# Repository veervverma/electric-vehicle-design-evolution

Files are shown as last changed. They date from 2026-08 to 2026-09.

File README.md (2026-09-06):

# Electric Vehicle Design Evolution

An educational CAD, visualization, 3D-printing, and conceptual aerodynamics portfolio tracing the development of an electric sedan and a Formula-style electric race-car study.

## Explore the project

- **[Interactive browser gallery](https://veervverma.github.io/electric-vehicle-design-evolution/):** displays both GLB and STL models, plays available glTF animations, and exposes every viewable model through a searchable catalog.
- **[Interactive W11 aerodynamic lab](https://veervverma.github.io/electric-vehicle-design-evolution/wind-tunnel.html):** places the detailed W11 reference model in an original browser wind-tunnel scene with automatic and keyboard-controlled vehicle motion, continuous solved-flow paths, front-to-diffuser tracing guides, speed telemetry, camera presets, and focused inspection modes.
- **[Version history](VERSIONS.md):** what changed from the first chassis sketches through Formula EV V6.
- **[Model catalog](MODEL_CATALOG.md):** recommended assembled files and direct repository links.
- **[Complete file manifest](FILE_MANIFEST.csv):** path, size, type, and SHA-256 digest for the preserved project artifacts.
- **[Generation and analysis tools](work/README.md):** the scripts used to build, convert, validate, estimate, and package the models.

## Best starting points

| Goal | Recommended file |
|---|---|
| View the final animated V5 car | [`outputs/formula_ev_v5_all_active_flaps/FORMULA_EV_V5_COMPLETE_SYNCED_AERO_FIXED.glb`](outputs/formula_ev_v5_all_active_flaps/FORMULA_EV_V5_COMPLETE_SYNCED_AERO_FIXED.glb) |
| Inspect the V6 CFD-preparation geometry | [`outputs/V6_CFD_REBUILD/V6_FULL_SCALE_CFD_PREVIEW.glb`](outputs/V6_CFD_REBUILD/V6_FULL_SCALE_CFD_PREVIEW.glb) |
| Print the repaired V6 at 8 inches | [`outputs/V6_PRINT_READY_5_TO_8_INCH/V6_8IN_PRINT_READY_SOLID_MM.3mf`](outputs/V6_PRINT_READY_5_TO_8_INCH/V6_8IN_PRINT_READY_SOLID_MM.3mf) |
| Print the repaired V6 at 5 inches | [`outputs/V6_PRINT_READY_5_TO_8_INCH/V6_5IN_PRINT_READY_SOLID_MM.3mf`](outputs/V6_PRINT_READY_5_TO_8_INCH/V6_5IN_PRINT_READY_SOLID_MM.3mf) |
| View the portfolio sedan | [`outputs/portfolio_ev_sedan_v3/EV_SEDAN_V3_COMPLETE_ASSEMBLED.stl`](outputs/portfolio_ev_sedan_v3/EV_SEDAN_V3_COMPLETE_ASSEMBLED.stl) |
| Inspect V5 print parts | [`outputs/FORMULA_EV_V5_PRINT_PARTS/`](outputs/FORMULA_EV_V5_PRINT_PARTS/) |
| View the final static W11/V6 hybrid | [`outputs/W11_V6_HYBRID_STATIC_8IN/W11_REFERENCE_V6_SYSTEMS_ASSEMBLED.glb`](outputs/W11_V6_HYBRID_STATIC_8IN/W11_REFERENCE_V6_SYSTEMS_ASSEMBLED.glb) |
| Print the final 8-inch modular hybrid | [`outputs/W11_V6_HYBRID_STATIC_8IN/W11_V6_ALL_PRINT_PARTS_220MM_PLATE.3mf`](outputs/W11_V6_HYBRID_STATIC_8IN/W11_V6_ALL_PRINT_PARTS_220MM_PLATE.3mf) |
| View the historically corrected W11 2020 rebuild | [`outputs/W11_2020_RESEARCH_REBUILD_STATIC_8IN/W11_2020_REFERENCE_RESEARCH_ASSEMBLED.glb`](outputs/W11_2020_RESEARCH_REBUILD_STATIC_8IN/W11_2020_REFERENCE_RESEARCH_ASSEMBLED.glb) |
| Print the corrected 29-piece W11 model | [`outputs/W11_2020_RESEARCH_REBUILD_STATIC_8IN/W11_2020_ALL_PRINT_PARTS_220MM_PLATE.3mf`](outputs/W11_2020_RESEARCH_REBUILD_STATIC_8IN/W11_2020_ALL_PRINT_PARTS_220MM_PLATE.3mf) |
| View the W11 2020 whole-car airflow presentation | [`outputs/W11_2020_AERO_CFD_VALIDATION_300KPH/W11_2020_WHOLE_CAR_AIRFLOW_PRESENTATION.glb`](outputs/W11_2020_AERO_CFD_VALIDATION_300KPH/W11_2020_WHOLE_CAR_AIRFLOW_PRESENTATION.glb) |
| Explore the interactive W11 wind tunnel | [Open the GitHub Pages aerodynamic lab](https://veervverma.github.io/electric-vehicle-design-evolution/wind-tunnel.html) |
| Review the solved SU2 CFD screening | [`outputs/W11_2020_AERO_CFD_VALIDATION_300KPH/CFD_VALIDATION_REPORT.md`](outputs/W11_2020_AERO_CFD_VALIDATION_300KPH/CFD_VALIDATION_REPORT.md) |

## Repository layout

```text
outputs/   Finished models, print files, previews, reports, CFD preparation, and data
work/      Reproducible Python generation, conversion, validation, and analysis scripts
docs/      Zero-build interactive model gallery for GitHub Pages
```

Every folder under `outputs/` includes its own `README.md` describing its purpose, important files, units, and limitations.

## File-format guide

- **GLB:** preferred for browser viewing, colors, named parts, and animation.
- **STL:** triangle geometry for slicers and GitHub's native STL viewer; STL does not store units.
- **3MF:** preferred for printing when available because it can preserve millimeter units, objects, and material assignments.
- **CSV/SVG/TXT:** conceptual analysis data, plots, reports, and assembly notes.
- **OpenFOAM case:** a prepared CFD starting point, not a completed or validated CFD result.
- **SU2/VTU/CSV:** reproducible CFD cases, ParaView-readable solved fields, and solver histories in the W11 2020 aerodynamic package.

## Accuracy and safety

This repository documents an educational design study—not a road-safe vehicle, homologated race car, validated aerodynamic package, or manufacturing release. The aerodynamic and lap-time outputs are reduced-order conceptual estimates unless a file explicitly states otherwise. The V6 OpenFOAM case was prepared but not solved. The W11 2020 aerodynamic package contains actual SU2 RANS screening, but it did not achieve mesh independence or physical wind-tunnel correlation and is not exact W11 performance data. Always inspect meshes in a slicer, confirm units, test tolerances, and perform appropriate engineering validation before fabrication or powered use.

## License

No open-source or fabrication license has been selected. The repository is provided as a portfolio record; copyright and reuse permission remain with the author unless a license is added later.

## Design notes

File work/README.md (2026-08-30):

# Generation and analysis tools

These Python scripts are the reproducible design record behind the files in `outputs/`. They use lightweight procedural mesh generation and standard-library exporters rather than a production CAD kernel.

| Script | Role |
|---|---|
| `advanced_sedan.py` | Builds the first advanced modular sedan. |
| `advanced_sedan_v2.py` | Builds the more detailed V2 sedan kit and assembled reference. |
| `portfolio_v3.py` | Adds EV systems and portfolio presentation outputs to the sedan branch. |
| `formula_ev.py` | Builds the Formula EV prototype and printable components. |
| `formula_ev_v2_glb.py` | Adds detailed systems, GLB export, named parts, and rear-DRS animation. |
| `formula_ev_v3_floor.py` | Adds the 2022–2025-inspired educational ground-effect floor study. |
| `formula_ev_v4_active_front.py` | Adds independent active front aero. |
| `formula_ev_v5_all_front_flaps.py` | Adds six active front flaps and the V5 complete models. |
| `export_v3_stl.py` | Exports assembled V3 geometry to STL. |
| `export_v5_print_stls.py` | Exports individual V5 print-part STLs. |
| `package_v5_print_kit.py` | Packages and documents the V5 print kit. |
| `export_formula_viewers.py` | Produces viewer-friendly Formula EV assets. |
| `embed_v6_actual_side_profile.py` | Updates V6 presentation geometry used in comparison visuals. |
| `rebuild_v6_cfd.py` | Rebuilds the full-scale V6 surfaces and OpenFOAM preparation package. |
| `make_v6_print_ready.py` | Repairs, reinforces, scales, solidifies, and validates the 5-inch and 8-inch V6 print models. |
| `build_w11_v6_static_hybrid.py` | Builds the static 8-inch W11-reference/V6-floor hybrid, complete EV chassis, rolling-wheel print kit, GLBs, STLs, 3MF, validation, and package archive. |
| `build_w11_2020_research_rebuild.py` | Replaces the V6 tunnel concept with a source-backed 2020 W11 flat/stepped floor, carbon-honeycomb chassis study, hybrid packaging, pushrod front suspension, swept pullrod rear suspension, and a complete 8-inch print/view package. |
| `build_w11_2020_su2_case.py` | Builds the full-scale, de-featured W11 2020 half-car meshes used for reproducible SU2 CFD screening. |
| `build_w11_2020_aero_outputs.py` | Builds the animated whole-car airflow presentation, equation estimate, solved-field figures, and force-history charts. |
| `build_w11_2020_validation_report.py` | Converts the solved SU2 histories into auditable force, grid-sensitivity, validation-status, and reproducibility reports. |
| `build_w11_2020_glbderived_cfd_v2.py` | Rebuilds the CFD shell directly from the supplied W11 GLB exterior and prepares the corrected full-car domain. |
| `render_w11_glbderived_cfd_figures.py` | Renders source-versus-CFD silhouette and corrected-shell reference figures. |
| `integrate_w11_su2_streamlines.py` | Integrates continuous streamlines from the solved SU2 velocity field and renders flow/side-plane figures. |
| `build_w11_glbderived_visuals.py` | Builds the exact-source overlay GLB and solver-derived continuous-airflow animated GLB. |
| `build_w11_glbderived_cfd_report.py` | Summarizes convergence, screening forces, geometry correction, assumptions, and validation limits. |
| `build_w11_glbderived_print_ready_8in.py` | Strengthens and scales the corrected shell to an exact 8-inch one-piece print, creates a three-section option and 3MF files, and builds the front-wing-to-diffuser airflow-point preview. |
| `audit_w11_reference.py` | Audits the supplied rendering mesh and documents why its raw shells are unsuitable for direct STL printing. |
| `audit_stl_mesh.py` | Audits STL topology, boundaries, degeneracy, dimensions, and shells. |
| `aero_estimate_v5.py` | Creates the first-order V5 force estimate. |
| `track_sim_v5.py` | Creates reduced-order track/lap estimates. |
| `v5_track_setups.py` | Creates Spa, Silverstone, and Monaco setup hypotheses. |
| `venturi_animation.py` | Creates the conceptual wind-tunnel/flow presentation animation. |
| `build_repository_docs.py` | Regenerates folder READMEs, manifests, and the browser gallery catalog. |

## Reproducibility note

The outputs reflect the scripts and assumptions at the time each version was created. Regeneration can replace files in `outputs/`; preserve a clean Git commit before rerunning a generator. Most earlier aerodynamic scripts implement conceptual reduced-order equations. The W11 2020 aero package adds actual SU2 RANS screening, but its documented mesh-convergence and physical-correlation limits mean it must not be represented as exact or wind-tunnel-validated W11 data.

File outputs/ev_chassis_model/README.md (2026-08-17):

# Early EV chassis and sedan visual studies

Rendered concept images documenting the transition from a bare skateboard chassis to an assembled sedan package.

## Recommended use

Use the isometric, side, rear, top, underbody, assembled, and exploded PNGs as visual development evidence.

## Units

Images only; no printable geometry is stored in this folder.

## Files

| File | Format | Purpose |
|---|---:|---|
| [`car_iso.png`](car_iso.png) | PNG | Rendered PNG view: car iso. |
| [`car_rear.png`](car_rear.png) | PNG | Rendered PNG view: car rear. |
| [`car_side.png`](car_side.png) | PNG | Rendered PNG view: car side. |
| [`parts_assembled.png`](parts_assembled.png) | PNG | Rendered PNG view: parts assembled. |
| [`parts_exploded.png`](parts_exploded.png) | PNG | Rendered PNG view: parts exploded. |
| [`preview_iso.png`](preview_iso.png) | PNG | Rendered PNG view: preview iso. |
| [`preview_rear.png`](preview_rear.png) | PNG | Rendered PNG view: preview rear. |
| [`preview_top.png`](preview_top.png) | PNG | Rendered PNG view: preview top. |
| [`sedan_bay.png`](sedan_bay.png) | PNG | Rendered PNG view: sedan bay. |
| [`sedan_iso.png`](sedan_iso.png) | PNG | Rendered PNG view: sedan iso. |
| [`sedan_rear.png`](sedan_rear.png) | PNG | Rendered PNG view: sedan rear. |
| [`sedan_side.png`](sedan_side.png) | PNG | Rendered PNG view: sedan side. |
| [`sedan_under.png`](sedan_under.png) | PNG | Rendered PNG view: sedan under. |

## Limitations

These are presentation renders rather than manufacturing or simulation files.

Return to the [repository version history](../../VERSIONS.md).

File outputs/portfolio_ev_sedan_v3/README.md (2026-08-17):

# Portfolio EV sedan V3

College-portfolio system model combining exterior design, skateboard battery packaging, rear e-axle motor and reduction gearbox, inverter, charging unit, suspension, brakes, interior, and exploded technical communication.

## Recommended use

Open `EV_SEDAN_V3_ASSEMBLED_SHOWCASE.3mf` for the color-coded assembly and `EV_SEDAN_V3_EXPLODED_TECHNICAL.3mf` for system explanation.

## Units

Millimeters for STL and 3MF geometry.

## Files

| File | Format | Purpose |
|---|---:|---|
| [`01_monocoque_body.stl`](01_monocoque_body.stl) | STL | Separate triangle-mesh part for 01 monocoque body; STL does not store units. |
| [`02_fastback_cabin.stl`](02_fastback_cabin.stl) | STL | Separate triangle-mesh part for 02 fastback cabin; STL does not store units. |
| [`03_removable_vented_hood.stl`](03_removable_vented_hood.stl) | STL | Separate triangle-mesh part for 03 removable vented hood; STL does not store units. |
| [`04_interior_tub.stl`](04_interior_tub.stl) | STL | Separate triangle-mesh part for 04 interior tub; STL does not store units. |
| [`05_swan_neck_rear_wing.stl`](05_swan_neck_rear_wing.stl) | STL | Separate triangle-mesh part for 05 swan neck rear wing; STL does not store units. |
| [`06_front_steering_suspension.stl`](06_front_steering_suspension.stl) | STL | Separate triangle-mesh part for 06 front steering suspension; STL does not store units. |
| [`07_rear_suspension.stl`](07_rear_suspension.stl) | STL | Separate triangle-mesh part for 07 rear suspension; STL does not store units. |
| [`08_tpu_tire_x4.stl`](08_tpu_tire_x4.stl) | STL | Separate triangle-mesh part for 08 tpu tire x4; STL does not store units. |
| [`09_sport_rim_x4.stl`](09_sport_rim_x4.stl) | STL | Separate triangle-mesh part for 09 sport rim x4; STL does not store units. |
| [`10_brake_rotor_x4.stl`](10_brake_rotor_x4.stl) | STL | Separate triangle-mesh part for 10 brake rotor x4; STL does not store units. |
| [`11_wheel_cap_x4.stl`](11_wheel_cap_x4.stl) | STL | Separate triangle-mesh part for 11 wheel cap x4; STL does not store units. |
| [`12_front_light_insert.stl`](12_front_light_insert.stl) | STL | Separate triangle-mesh part for 12 front light insert; STL does not store units. |
| [`13_rear_light_insert.stl`](13_rear_light_insert.stl) | STL | Separate triangle-mesh part for 13 rear light insert; STL does not store units. |
| [`14_mirror_x2.stl`](14_mirror_x2.stl) | STL | Separate triangle-mesh part for 14 mirror x2; STL does not store units. |
| [`15_skateboard_battery_pack.stl`](15_skateboard_battery_pack.stl) | STL | Separate triangle-mesh part for 15 skateboard battery pack; STL does not store units. |
| [`16_rear_motor_gearbox.stl`](16_rear_motor_gearbox.stl) | STL | Separate triangle-mesh part for 16 rear motor gearbox; STL does not store units. |
| [`17_inverter_controller.stl`](17_inverter_controller.stl) | STL | Separate triangle-mesh part for 17 inverter controller; STL does not store units. |
| [`18_charging_service_unit.stl`](18_charging_service_unit.stl) | STL | Separate triangle-mesh part for 18 charging service unit; STL does not store units. |
| [`assembled_showcase.svg`](assembled_showcase.svg) | SVG | Scalable vector presentation graphic or chart: assembled showcase. |
| [`EV_SEDAN_V3_ASSEMBLED_SHOWCASE.3mf`](EV_SEDAN_V3_ASSEMBLED_SHOWCASE.3mf) | 3MF | Color/material presentation 3MF for assembled viewing and slicer import. |
| [`EV_SEDAN_V3_COMPLETE_ASSEMBLED.stl`](EV_SEDAN_V3_COMPLETE_ASSEMBLED.stl) | STL | Combined triangle-mesh reference of the complete design; read this folder's unit and print limitations. |
| [`EV_SEDAN_V3_EXPLODED_REFERENCE.stl`](EV_SEDAN_V3_EXPLODED_REFERENCE.stl) | STL | Separate triangle-mesh part for ev sedan v3 exploded reference; STL does not store units. |
| [`EV_SEDAN_V3_EXPLODED_TECHNICAL.3mf`](EV_SEDAN_V3_EXPLODED_TECHNICAL.3mf) | 3MF | 3MF presentation project with systems arranged in an exploded technical layout. |
| [`exploded_technical.svg`](exploded_technical.svg) | SVG | Scalable vector presentation graphic or chart: exploded technical. |
| [`PORTFOLIO_NOTES.txt`](PORTFOLIO_NOTES.txt) | TXT | Documentation, assumptions, guide, or report: portfolio notes. |

## Limitations

Educational scale prototype. Powered operation requires independent tolerance, thermal, electrical, and structural engineering.

Return to the [repository version history](../../VERSIONS.md).

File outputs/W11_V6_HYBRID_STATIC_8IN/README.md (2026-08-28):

# W11 / V6 STATIC 8-INCH HYBRID

This package combines the supplied high-detail 2020 Mercedes-style exterior reference with a newly built, printable V6-derived twin-Venturi floor and a complete educational EV chassis. The design is **static**: there are no DRS or active-front-wing animations. The four printed wheels can rotate on separate axle pins.

## Start here

- `W11_REFERENCE_V6_SYSTEMS_ASSEMBLED.glb` — best high-detail exterior view with named floor/chassis systems.
- `W11_REFERENCE_V6_SYSTEMS_EXPLODED.glb` — exterior lifted so the chassis and floor are easy to inspect.
- `W11_V6_PRINTABLE_ASSEMBLED.glb` — exact procedural geometry represented by the printable files.
- `W11_V6_PRINTABLE_EXPLODED.glb` — exact print parts separated for inspection.
- `W11_V6_ALL_PRINT_PARTS_220MM_PLATE.3mf` — all 25 physical parts arranged on one 220 x 220 mm plate; units are explicitly millimetres.
- `STL_PRINT_PARTS/` — one STL per unique part, with x4 quantities in filenames.
- `GLB_INDIVIDUAL_PARTS/` — each printable part as an individually viewable GLB.

## Finished size

Nominal overall length: **203.2 mm / 8.00 in**. Approximate assembled envelope: 203.20 x 74.80 x 40.05 mm. STL files do not store units, so choose **millimetres** when importing. The 3MF declares millimetres directly.

## Recommended material and settings

- Best simple choice: **PLA+** for all rigid parts.
- Optional upgrade: **PETG** for axle pins, retainers and suspension; **TPU 95A** for the four wheels.
- 0.4 mm nozzle; 0.16-0.20 mm layers; 3-4 walls; 18-25% gyroid infill.
- Use tree/build-plate supports for the body, halo, wings and suspension.
- Print the floor with its broad upper face on the bed so the Venturi channels face upward; rotate after slicing only if your support preview is cleaner.

## Assembly order

1. Fit the low energy store, motor and inverter into the structural chassis.
2. Attach the chassis to the upper face of the twin-Venturi floor. Keep the floor removable if you want the tunnels visible.
3. Attach front and rear suspension at the marked axle stations, approximately X=-53.6 mm and X=+76.2 mm.
4. Glue axle pins into the uprights. Slide on wheels; glue retainers only to the pin tips. Leave about 0.25-0.35 mm lateral play.
5. Fit cockpit insert and halo to the upper body, then attach the removable nose.
6. Place the upper body over the chassis. Attach the static front and rear wings last.

## What is and is not copied

The supplied GLB is retained as the detailed visual exterior in the two `W11_REFERENCE...` files. It is a rendering mesh rather than watertight CAD. The printable body is therefore a strengthened, simplified derivative matched to the reference silhouette; it is not a direct raw conversion of the fragile source mesh. The V6 tunnel/plank/diffuser architecture is newly rebuilt for this 8-inch model and is not validated CFD or structural engineering.

## Reference credit

Original Sketchfab model: `mercedec f1 2020` by Kevin Love SketchFab / Tyler_Kevin, licensed CC BY 4.0: https://sketchfab.com/3d-models/mercedec-f1-2020-0d97207d829441ba95952598f84e8d63

Source GLB SHA-256: `f63aa9ab4a1225080b5968ebbaa7aeb1bc909b506e1cae9d41df6a08b38ec11f`

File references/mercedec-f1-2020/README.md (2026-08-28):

# Mercedes-style F1 2020 exterior reference

This folder preserves the self-contained GLB supplied by the user for the W11/V6 hybrid design study.

- Original title: **mercedec f1 2020**
- Creator: **Kevin Love SketchFab / Tyler_Kevin**
- Source: https://sketchfab.com/3d-models/mercedec-f1-2020-0d97207d829441ba95952598f84e8d63
- License: **Creative Commons Attribution 4.0 International (CC BY 4.0)**
- License URL: https://creativecommons.org/licenses/by/4.0/

The GLB is a textured rendering mesh, not watertight manufacturing CAD. It is retained as the detailed visual exterior. The repository's 8-inch printable body and internal systems are separately generated and documented under `outputs/W11_V6_HYBRID_STATIC_8IN/`.

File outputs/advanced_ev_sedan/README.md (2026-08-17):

# Advanced EV sedan V1

First modular printable fastback sedan with separate structural, body, wheel, suspension, and retaining components.

## Recommended use

Start with `advanced_ev_sedan_print_plate.3mf` for printing or `advanced_sedan_assembled_reference.stl` for inspection.

## Units

Model dimensions are intended as millimeters. Prefer the 3MF print plate when available because 3MF records units.

## Files

| File | Format | Purpose |
|---|---:|---|
| [`advanced_body.stl`](advanced_body.stl) | STL | Separate triangle-mesh part for advanced body; STL does not store units. |
| [`advanced_ev_sedan_kit.3mf`](advanced_ev_sedan_kit.3mf) | 3MF | 3MF print project preserving object structure and millimeter units where authored. |
| [`advanced_ev_sedan_print_plate.3mf`](advanced_ev_sedan_print_plate.3mf) | 3MF | 3MF print project preserving object structure and millimeter units where authored. |
| [`advanced_sedan_assembled_reference.stl`](advanced_sedan_assembled_reference.stl) | STL | Combined triangle-mesh reference of the complete design; read this folder's unit and print limitations. |
| [`fastback_cabin.stl`](fastback_cabin.stl) | STL | Separate triangle-mesh part for fastback cabin; STL does not store units. |
| [`PRINT_AND_ASSEMBLY.txt`](PRINT_AND_ASSEMBLY.txt) | TXT | Documentation, assumptions, guide, or report: print and assembly. |
| [`rear_wing.stl`](rear_wing.stl) | STL | Separate triangle-mesh part for rear wing; STL does not store units. |
| [`sport_wheel_x4.stl`](sport_wheel_x4.stl) | STL | Separate triangle-mesh part for sport wheel x4; STL does not store units. |
| [`suspension_axle_module_x2.stl`](suspension_axle_module_x2.stl) | STL | Separate triangle-mesh part for suspension axle module x2; STL does not store units. |
| [`wheel_retainer_cap_x4.stl`](wheel_retainer_cap_x4.stl) | STL | Separate triangle-mesh part for wheel retainer cap x4; STL does not store units. |

## Limitations

Educational display model; test fit all moving or retained interfaces before a complete print.

Return to the [repository version history](../../VERSIONS.md).

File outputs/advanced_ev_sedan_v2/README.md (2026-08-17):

# Advanced EV sedan V2

More detailed modular sedan with monocoque, fastback cabin, removable vented hood, interior, swan-neck wing, steering/suspension, wheels, brakes, lights, mirrors, battery tray, and 130-size motor cradle.

## Recommended use

Use `advanced_ev_sedan_v2_WHITE_FIXED.3mf` for the corrected white viewer/print project, the kit 3MF for separate objects, and the assembled STL as a reference.

## Units

Millimeters. The assembled envelope is approximately 195 × 105 × 70 mm.

## Files

| File | Format | Purpose |
|---|---:|---|
| [`01_monocoque_body.stl`](01_monocoque_body.stl) | STL | Separate triangle-mesh part for 01 monocoque body; STL does not store units. |
| [`02_fastback_cabin.stl`](02_fastback_cabin.stl) | STL | Separate triangle-mesh part for 02 fastback cabin; STL does not store units. |
| [`03_removable_vented_hood.stl`](03_removable_vented_hood.stl) | STL | Separate triangle-mesh part for 03 removable vented hood; STL does not store units. |
| [`04_interior_tub.stl`](04_interior_tub.stl) | STL | Separate triangle-mesh part for 04 interior tub; STL does not store units. |
| [`05_swan_neck_rear_wing.stl`](05_swan_neck_rear_wing.stl) | STL | Separate triangle-mesh part for 05 swan neck rear wing; STL does not store units. |
| [`06_front_steering_suspension.stl`](06_front_steering_suspension.stl) | STL | Separate triangle-mesh part for 06 front steering suspension; STL does not store units. |
| [`07_rear_suspension.stl`](07_rear_suspension.stl) | STL | Separate triangle-mesh part for 07 rear suspension; STL does not store units. |
| [`08_tpu_tire_x4.stl`](08_tpu_tire_x4.stl) | STL | Separate triangle-mesh part for 08 tpu tire x4; STL does not store units. |
| [`09_sport_rim_x4.stl`](09_sport_rim_x4.stl) | STL | Separate triangle-mesh part for 09 sport rim x4; STL does not store units. |
| [`10_brake_rotor_x4.stl`](10_brake_rotor_x4.stl) | STL | Separate triangle-mesh part for 10 brake rotor x4; STL does not store units. |
| [`11_wheel_cap_x4.stl`](11_wheel_cap_x4.stl) | STL | Separate triangle-mesh part for 11 wheel cap x4; STL does not store units. |
| [`12_front_light_insert.stl`](12_front_light_insert.stl) | STL | Separate triangle-mesh part for 12 front light insert; STL does not store units. |
| [`13_rear_light_insert.stl`](13_rear_light_insert.stl) | STL | Separate triangle-mesh part for 13 rear light insert; STL does not store units. |
| [`14_mirror_x2.stl`](14_mirror_x2.stl) | STL | Separate triangle-mesh part for 14 mirror x2; STL does not store units. |
| [`advanced_ev_sedan_v2_kit.3mf`](advanced_ev_sedan_v2_kit.3mf) | 3MF | 3MF print project preserving object structure and millimeter units where authored. |
| [`advanced_ev_sedan_v2_WHITE.3mf`](advanced_ev_sedan_v2_WHITE.3mf) | 3MF | Color/material presentation 3MF for assembled viewing and slicer import. |
| [`advanced_ev_sedan_v2_WHITE_FIXED.3mf`](advanced_ev_sedan_v2_WHITE_FIXED.3mf) | 3MF | Color/material presentation 3MF for assembled viewing and slicer import. |
| [`advanced_sedan_v2_assembled_reference.stl`](advanced_sedan_v2_assembled_reference.stl) | STL | Combined triangle-mesh reference of the complete design; read this folder's unit and print limitations. |
| [`PRINT_GUIDE.txt`](PRINT_GUIDE.txt) | TXT | Documentation, assumptions, guide, or report: print guide. |

## Limitations

The motor-to-wheel drivetrain remains a custom engineering step; this is not a road-safe or validated RC-car design.

Return to the [repository version history](../../VERSIONS.md).

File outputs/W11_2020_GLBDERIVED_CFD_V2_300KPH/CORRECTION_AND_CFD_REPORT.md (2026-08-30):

# Corrected W11 GLB-derived aerodynamic CFD study

## Why the earlier CFD geometry was wrong

The earlier run replaced the supplied W11 rendering mesh with boxes, ellipsoids and generic airfoil primitives. That was done because the raw GLB contains **185,289 triangles, 14,021 boundary edges and 24,930 non-manifold edges**, making it unsuitable as a direct CFD volume boundary. The simplification made meshing fast and stable, but it did **not** satisfy the request to redesign the complete car from the supplied W11 GLB. That was a scope error, not a limitation that should have been hidden.

## What is corrected

- The new surface begins with **116,006 source triangles** covering the exterior body, nose, front wing, floor, diffuser, rear wing and tyres.
- A 20 mm full-scale voxel union seals the rendering gaps; marching cubes and light Taubin smoothing produce one watertight, winding-consistent shell.
- Final CFD boundary: **260,304 triangles**, approximately **5.64 × 1.98 × 1.10 m**.
- No box/ellipsoid vehicle surrogate is used.
- The wind-tunnel domain is full-car, not a half-car symmetry approximation: **320,259 nodes and 1,634,564 tetrahedra**.
- `W11_SOURCE_TO_CFD_SURFACE_OVERLAY.glb` overlays the translucent CFD shell directly on the exact textured source GLB.

## Continuous airflow

`W11_SOURCE_WITH_SOLVER_DERIVED_CONTINUOUS_AIRFLOW.glb` uses continuous tubes obtained by integrating the solved SU2 nodal velocity field. The colored tubes are the CFD-derived streamlines. Animated white pulses travel along those tubes only to show direction; they do not replace or fabricate the solved flow path.

The streamline integration uses inverse-distance velocity interpolation and midpoint stepping. The package includes **40 continuous streamlines**, including **9 floor/diffuser-seeded lines** and **9 additional solved-field paths selected to run from the front-wing region into the floor and through the diffuser**. These paths are traced in both directions from in-field seeds so a solid front-wing cell cannot numerically terminate them before they enter the underbody.

## CFD setup

- SU2 8.5.0, steady incompressible RANS, SST V2003m.
- 300 km/h / 83.333 m/s, density 1.225 kg/m³.
- Full-car domain with moving ground at freestream speed.
- Stationary wheel envelope, no cooling flow and no wheel deformation.
- 80 iterations at CFL 1 followed by 80 restarted iterations at CFL 3.

## Screening force status

Final 20-iteration mean: `CL = -0.3188 ± 0.1214`, `CD = 1.8138 ± 0.0664` using a 1.50 m² reference area. The corresponding raw screening forces at 300 km/h are **2.03 kN downforce** and **11.57 kN drag**.

These force values are **not validated performance predictions**. Drag-Cauchy convergence was not reached (0.00639 vs 0.0002); no prism-layer/y+ study, rotating-wheel model, additional mesh levels, or wind-tunnel correlation was completed. The continuous flow geometry is useful for design communication, but the forces must not be represented as actual Mercedes W11 data.

## Public source and attribution

- Supplied visual model: *mercedec f1 2020* by Kevin Love SketchFab / Tyler_Kevin, CC BY 4.0.
- Source: <https://sketchfab.com/3d-models/mercedec-f1-2020-0d97207d829441ba95952598f84e8d63>
- FIA 2020 Technical Regulations: <https://www.fia.com/file/80070/download>
- SU2 8.5.0: <https://github.com/su2code/SU2/releases/tag/v8.5.0>
- Gmsh: <https://gmsh.info/>

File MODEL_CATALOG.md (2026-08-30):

# Model catalog

The GitHub Pages gallery reads `docs/models.json` and can display every GLB and STL below the `outputs/` tree. This shorter table highlights assembled models and major study views. Click an STL in the GitHub repository for GitHub's native 3D viewer, or use the Pages gallery for searchable GLB/STL viewing and glTF animation playback.

| Design family | Model | Format | Purpose |
|---|---|---:|---|
| Advanced EV sedan V1 | [`advanced_sedan_assembled_reference.stl`](outputs/advanced_ev_sedan/advanced_sedan_assembled_reference.stl) | STL | Combined triangle-mesh reference of the complete design; read this folder's unit and print limitations. |
| Advanced EV sedan V2 | [`advanced_sedan_v2_assembled_reference.stl`](outputs/advanced_ev_sedan_v2/advanced_sedan_v2_assembled_reference.stl) | STL | Combined triangle-mesh reference of the complete design; read this folder's unit and print limitations. |
| Portfolio EV sedan V3 | [`EV_SEDAN_V3_COMPLETE_ASSEMBLED.stl`](outputs/portfolio_ev_sedan_v3/EV_SEDAN_V3_COMPLETE_ASSEMBLED.stl) | STL | Combined triangle-mesh reference of the complete design; read this folder's unit and print limitations. |
| Formula EV prototype / V1 | [`FORMULA_EV_COMPLETE_ASSEMBLED.stl`](outputs/formula_ev_prototype/FORMULA_EV_COMPLETE_ASSEMBLED.stl) | STL | Combined triangle-mesh reference of the complete design; read this folder's unit and print limitations. |
| Formula EV prototype / V1 | [`FORMULA_EV_DETAILED_VIEWER.glb`](outputs/formula_ev_prototype/FORMULA_EV_DETAILED_VIEWER.glb) | GLB | Browser-viewable binary glTF model for the formula ev detailed viewer component/system. |
| Formula EV V2 — detailed GLB and rear DRS | [`FORMULA_EV_V2_COMPLETE_ANIMATED_DRS.glb`](outputs/formula_ev_v2_detailed/FORMULA_EV_V2_COMPLETE_ANIMATED_DRS.glb) | GLB | Browser-viewable binary glTF model of the complete assembly; may contain animation. |
| Formula EV V3 — 2022–2025-inspired floor study | [`FORMULA_EV_V3_COMPLETE_2022_2025_FLOOR.glb`](outputs/formula_ev_v3_2022_2025_floor/FORMULA_EV_V3_COMPLETE_2022_2025_FLOOR.glb) | GLB | Browser-viewable binary glTF model of the complete assembly. |
| Formula EV V3 — 2022–2025-inspired floor study | [`FORMULA_EV_V3_COMPLETE_UNDERFLOOR.glb`](outputs/formula_ev_v3_2022_2025_floor/FORMULA_EV_V3_COMPLETE_UNDERFLOOR.glb) | GLB | Browser-viewable binary glTF model of the complete assembly. |
| Formula EV V3 — 2022–2025-inspired floor study | [`FORMULA_EV_V3_EXPLODED_UNDERFLOOR.glb`](outputs/formula_ev_v3_2022_2025_floor/FORMULA_EV_V3_EXPLODED_UNDERFLOOR.glb) | GLB | Browser-viewable binary glTF model in an exploded technical layout. |
| Formula EV V4 — dual active aero | [`FORMULA_EV_V4_COMPLETE_DUAL_ACTIVE_AERO.glb`](outputs/formula_ev_v4_dual_active_aero/FORMULA_EV_V4_COMPLETE_DUAL_ACTIVE_AERO.glb) | GLB | Browser-viewable binary glTF model of the complete assembly; may contain animation. |
| Formula EV V5 — six active front flaps and synchronized assembly | [`FORMULA_EV_V5_COMPLETE_ACTIVE_FRONT_WING.glb`](outputs/formula_ev_v5_all_active_flaps/FORMULA_EV_V5_COMPLETE_ACTIVE_FRONT_WING.glb) | GLB | Browser-viewable binary glTF model of the complete assembly; may contain animation. |
| Formula EV V5 — six active front flaps and synchronized assembly | [`FORMULA_EV_V5_COMPLETE_ALL_ACTIVE_FLAPS.glb`](outputs/formula_ev_v5_all_active_flaps/FORMULA_EV_V5_COMPLETE_ALL_ACTIVE_FLAPS.glb) | GLB | Browser-viewable binary glTF model of the complete assembly; may contain animation. |
| Formula EV V5 — six active front flaps and synchronized assembly | [`FORMULA_EV_V5_COMPLETE_SYNCED_AERO_FIXED.glb`](outputs/formula_ev_v5_all_active_flaps/FORMULA_EV_V5_COMPLETE_SYNCED_AERO_FIXED.glb) | GLB | Browser-viewable binary glTF model of the complete assembly; may contain animation. |
| Formula EV V5 — wind-tunnel animation and reduced-order track study | [`V5_VENTURI_WIND_TUNNEL_ANIMATION.glb`](outputs/v5_wind_tunnel_and_track_sim/V5_VENTURI_WIND_TUNNEL_ANIMATION.glb) | GLB | Browser-viewable binary glTF model containing the conceptual airflow presentation; may contain animation. |
| Formula EV V6 — full-scale CFD-preparation rebuild | [`V6_FULL_SCALE_CFD_PREVIEW.glb`](outputs/V6_CFD_REBUILD/V6_FULL_SCALE_CFD_PREVIEW.glb) | GLB | Browser-viewable binary glTF model for the v6 full scale cfd preview component/system. |
| Formula EV V6 — repaired 5-inch and 8-inch print release | [`V6_5IN_PRINT_READY_SOLID_MM.stl`](outputs/V6_PRINT_READY_5_TO_8_INCH/V6_5IN_PRINT_READY_SOLID_MM.stl) | STL | Validated manifold STL prepared for FDM slicing; import as millimeters. |
| Formula EV V6 — repaired 5-inch and 8-inch print release | [`V6_8IN_PRINT_READY_SOLID_MM.stl`](outputs/V6_PRINT_READY_5_TO_8_INCH/V6_8IN_PRINT_READY_SOLID_MM.stl) | STL | Validated manifold STL prepared for FDM slicing; import as millimeters. |
| W11 reference / V6 — static 8-inch printable hybrid | [`W11_REFERENCE_V6_SYSTEMS_ASSEMBLED.glb`](outputs/W11_V6_HYBRID_STATIC_8IN/W11_REFERENCE_V6_SYSTEMS_ASSEMBLED.glb) | GLB | Browser-viewable binary glTF model of the complete assembly. |
| W11 reference / V6 — static 8-inch printable hybrid | [`W11_V6_PRINTABLE_ASSEMBLED.glb`](outputs/W11_V6_HYBRID_STATIC_8IN/W11_V6_PRINTABLE_ASSEMBLED.glb) | GLB | Browser-viewable binary glTF model of the complete assembly. |
| W11 reference / V6 — static 8-inch printable hybrid | [`W11_V6_PRINTABLE_ASSEMBLED_REFERENCE.stl`](outputs/W11_V6_HYBRID_STATIC_8IN/W11_V6_PRINTABLE_ASSEMBLED_REFERENCE.stl) | STL | Combined triangle-mesh reference of the complete design; read this folder's unit and print limitations. |
| W11 2020 — open-source research rebuild, static 8-inch print model | [`W11_2020_PRINTABLE_ASSEMBLED.glb`](outputs/W11_2020_RESEARCH_REBUILD_STATIC_8IN/W11_2020_PRINTABLE_ASSEMBLED.glb) | GLB | Browser-viewable binary glTF model of the complete assembly. |
| W11 2020 — open-source research rebuild, static 8-inch print model | [`W11_2020_PRINTABLE_ASSEMBLED_REFERENCE.stl`](outputs/W11_2020_RESEARCH_REBUILD_STATIC_8IN/W11_2020_PRINTABLE_ASSEMBLED_REFERENCE.stl) | STL | Combined triangle-mesh reference of the complete design; read this folder's unit and print limitations. |
| W11 2020 — open-source research rebuild, static 8-inch print model | [`W11_2020_REFERENCE_RESEARCH_ASSEMBLED.glb`](outputs/W11_2020_RESEARCH_REBUILD_STATIC_8IN/W11_2020_REFERENCE_RESEARCH_ASSEMBLED.glb) | GLB | Browser-viewable binary glTF model of the complete assembly. |
| W11 2020 — 300 km/h aerodynamic visualization and SU2 CFD screening | [`W11_2020_WHOLE_CAR_AIRFLOW_PRESENTATION.glb`](outputs/W11_2020_AERO_CFD_VALIDATION_300KPH/W11_2020_WHOLE_CAR_AIRFLOW_PRESENTATION.glb) | GLB | Browser-viewable binary glTF model containing the explanatory airflow presentation. |

The interactive catalog currently indexes **411** GLB/STL files.

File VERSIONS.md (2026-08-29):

# Design version history

## Sedan design branch

| Stage | Folder | Purpose and major change |
|---|---|---|
| Visual chassis studies | [`outputs/ev_chassis_model`](outputs/ev_chassis_model/) | Early skateboard-chassis, sedan packaging, and exploded-layout reference renders. |
| Advanced sedan V1 | [`outputs/advanced_ev_sedan`](outputs/advanced_ev_sedan/) | First modular printable fastback sedan with separate body, cabin, wing, wheels, suspension/axle modules, and retainers. |
| Advanced sedan V2 | [`outputs/advanced_ev_sedan_v2`](outputs/advanced_ev_sedan_v2/) | More complex monocoque, removable hood, interior, steering/suspension, detailed wheels and brakes, lights, mirrors, and motor cradle. Includes repaired white 3MF. |
| Portfolio sedan V3 | [`outputs/portfolio_ev_sedan_v3`](outputs/portfolio_ev_sedan_v3/) | System-level college portfolio model adding the battery pack, rear motor/gearbox, inverter, charging unit, assembled and exploded references, and presentation drawings. |

## Formula EV design branch

| Version | Folder | Purpose and major change |
|---|---|---|
| Prototype / V1 | [`outputs/formula_ev_prototype`](outputs/formula_ev_prototype/) | New open-wheel EV architecture with monocoque, detachable nose, wings, halo, suspension, wheels, battery, motor/gearbox, inverter, printable parts, assembled STL/3MF, and GLB viewer. |
| V2 detailed | [`outputs/formula_ev_v2_detailed`](outputs/formula_ev_v2_detailed/) | Higher-detail GLB presentation model with named individual systems and animated rear DRS. |
| V3 floor study | [`outputs/formula_ev_v3_2022_2025_floor`](outputs/formula_ev_v3_2022_2025_floor/) | Original educational interpretation of 2022–2025 ground-effect ideas: twin Venturi tunnels, fences, floor edge, plank/skids, diffuser, and underfloor study files. |
| V4 dual active aero | [`outputs/formula_ev_v4_dual_active_aero`](outputs/formula_ev_v4_dual_active_aero/) | Adds independent front active-aero flaps and actuator while retaining rear DRS. |
| V5 all active flaps | [`outputs/formula_ev_v5_all_active_flaps`](outputs/formula_ev_v5_all_active_flaps/) | Six moving front flaps, rear DRS, synchronized whole-car fix, individual GLBs, and 55-part 3MF print kits. |
| V5 print parts | [`outputs/FORMULA_EV_V5_PRINT_PARTS`](outputs/FORMULA_EV_V5_PRINT_PARTS/) | Separate STL export of the complete 55-part V5 assembly with parts/material manifest. |
| V5 conceptual studies | [`outputs/aero_estimate_v5`](outputs/aero_estimate_v5/), [`outputs/v5_track_setups_spa_silverstone_monaco`](outputs/v5_track_setups_spa_silverstone_monaco/), [`outputs/v5_wind_tunnel_and_track_sim`](outputs/v5_wind_tunnel_and_track_sim/) | First-order force estimates, track-specific setup hypotheses, reduced-order lap estimates, and a presentation airflow animation. These are not CFD validation. |
| V6 full-scale CFD rebuild | [`outputs/V6_CFD_REBUILD`](outputs/V6_CFD_REBUILD/) | Parametric 5.45 m Formula EV geometry, separated aerodynamic surfaces, preview GLB, manifest, and prepared 300 km/h OpenFOAM case. This is CFD preparation, not a solved case. |
| V6 repaired print release | [`outputs/V6_PRINT_READY_5_TO_8_INCH`](outputs/V6_PRINT_READY_5_TO_8_INCH/) | Solidified and topology-checked 5-inch and 8-inch derivatives of the V6 model, with explicit-millimeter 3MFs and validated STL alternatives. |
| W11/V6 static 8-inch hybrid | [`outputs/W11_V6_HYBRID_STATIC_8IN`](outputs/W11_V6_HYBRID_STATIC_8IN/) | Final static study using the supplied high-detail W11-style exterior as a visual reference while adding a new printable twin-Venturi floor, full EV chassis, energy store, rear motor/gearbox, inverter, suspension, rolling wheels, individual GLBs/STLs, and a one-plate 3MF kit. |
| W11 2020 research rebuild | [`outputs/W11_2020_RESEARCH_REBUILD_STATIC_8IN`](outputs/W11_2020_RESEARCH_REBUILD_STATIC_8IN/) | Source-backed correction using the FIA 2020 floor rules, Mercedes chassis specifications and contemporary W11 technical analysis. Replaces the anachronistic tunnel floor and EV frame with a flat stepped floor, plank, bargeboards, short diffuser, carbon-honeycomb survival cell, compact hybrid packaging, pushrod front suspension and swept pullrod rear suspension. |
| W11 2020 aerodynamic CFD screening | [`outputs/W11_2020_AERO_CFD_VALIDATION_300KPH`](outputs/W11_2020_AERO_CFD_VALIDATION_300KPH/) | Reruns the latest W11 reference design as a de-featured full-scale half-car surrogate: animated airflow presentation, transparent equation estimate, coarse and medium SU2 RANS/SST meshes, stationary/moving-ground diagnostics, solved fields, grid sensitivity, and explicit validation limits. |

## Important distinction between V5 and V6

V5 is primarily a detailed presentation/animation and multi-part printing model. V6 is a separate full-scale CFD-preparation rebuild with a different parametric geometry pipeline. The later V6 print files are scaled, reinforced, and solidified derivatives made specifically because the full-scale CFD surface export was too large and unsuitable for a consumer slicer.

The W11/V6 hybrid is a separate static integration branch. Its textured exterior GLB is retained for high-detail viewing under CC BY 4.0 attribution, while the print parts are newly generated and strengthened rather than being a direct raw STL conversion of the non-watertight rendering mesh.

The later W11 2020 research rebuild corrects the hybrid branch's historical mismatch: 2020 cars used a regulated reference/step-plane floor and short diffuser rather than the deep 2022-style Venturi tunnels. It keeps the 8-inch static print format while changing the floor, chassis, hybrid packaging and suspension architecture.

The aerodynamic package advances that research rebuild from presentation-only airflow to a real open-source SU2 CFD screening exercise at 300 km/h. The coarse moving-ground case passed its force-Cauchy target, but the medium case did not and the coarse/medium ClA spread remained about 30%; therefore the result is numerical screening rather than mesh-independent or wind-tunnel-validated W11 data.

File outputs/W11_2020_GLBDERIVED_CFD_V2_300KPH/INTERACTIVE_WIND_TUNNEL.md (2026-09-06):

# Interactive W11 aerodynamic lab

Public viewer: <https://veervverma.github.io/electric-vehicle-design-evolution/wind-tunnel.html>

## Purpose

This page combines the supplied detailed W11 visual model with the latest GLB-derived aerodynamic screening data in an accessible browser presentation. It is designed for visual inspection and portfolio communication, not as a replacement for a CFD solver or physical wind tunnel.

## Controls

- **Drive + Flow:** starts an automatic moving presentation of the W11 with its CFD overlay attached. Press `WASD` or the arrow keys—or hold the on-screen direction buttons—to take manual control. `Space` brakes, `R` resets and `M` toggles the automatic tour.
- **Full Flow:** returns the car to the wind-tunnel datum and shows all 40 solver-integrated flow paths, ambient freestream points and the W11.
- **Front to Diffuser:** isolates the solver-derived floor/diffuser paths and the disclosed upstream continuity traces.
- **Car Inspection:** hides airflow so the detailed source car can be inspected.
- **ISO / Side / Top / Floor:** moves between fixed inspection views while preserving mouse or touch orbiting.
- **Air Speed:** changes particle travel rate and recalculates dynamic pressure using `q = 1/2 rho V^2` at 1.225 kg/m³.
- **Flow Density / Display switches:** reduce animated points or hide path lines, freestream points and the tunnel reference scene.

## Data provenance

- The cyan and green geometry comes from `CFD_RESULTS/SOLVER_DERIVED_STREAMLINES.json`.
- The 40 displayed CFD paths were integrated from the 300 km/h SU2 screening field.
- Orange paths retain each solved floor/diffuser segment but add a smooth upstream visualization guide from ahead of the front wing because the coarse, unconverged field terminated the original floor-seeded integration farther downstream.
- The speed slider does **not** recompute the flow field. It only scales presentation motion and the equation-based dynamic-pressure readout.

## Validation status

The CFD run did not satisfy its convergence target, mesh independence, rotating-wheel treatment, boundary-layer study, or physical wind-tunnel correlation. Therefore neither this page nor the underlying results should be represented as measured Mercedes W11 aerodynamic performance.

## Implementation and attribution

The page is an original Three.js implementation. Its compact mode-selector presentation was inspired by Patrick Heintzmann's public Formula demo, but no source code, branded assets or car model were copied from that site. The W11 visual reference is *mercedec f1 2020* by Kevin Love SketchFab / Tyler_Kevin under CC BY 4.0; full attribution is preserved in `REFERENCE_LICENSE_AND_ATTRIBUTION.txt`.

The supplied W11 GLB contains one fused mesh rather than four independently transformable wheel objects. Drive mode now animates the actual tyre, rim, hub and brake-disc vertices around the measured front and rear axle centers while leaving the brake calipers fixed. The front wheel geometry also steers during turns. This preserves the source textures—including the rotating tyre sidewall markings—without replacing the W11 with a generic wheel model. The attached CFD overlay moves with the presentation rig, but this motion is not a moving-body CFD recomputation.

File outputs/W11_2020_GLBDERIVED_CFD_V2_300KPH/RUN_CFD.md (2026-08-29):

# Reproducing the corrected full-car SU2 screening run

## Requirements

- SU2 8.5.0 with `SU2_CFD` available on the command line.
- Approximately 15 GB free working space and enough memory for a 1.63-million-tetrahedron incompressible RANS case.

## Initial 80 iterations

1. Copy the two configuration files and `W11_2020_GLBDERIVED_FULL_DOMAIN.su2.gz` into an empty working folder.
2. Decompress the mesh and rename it `w11_glb_faithful_full.su2`.
3. Run `SU2_CFD w11_glb_faithful_moving_ground.cfg`.

## Restarted 80 iterations

After the initial run has written `restart_w11_glb_faithful.dat`, run:

`SU2_CFD w11_glb_faithful_continue.cfg`

The restart raises CFL from 1 to 3 and writes separate `*_continue` histories and fields. Retain both histories when evaluating convergence. A completed run is not automatically a validated result: inspect residuals and force histories, repeat on multiple mesh levels, add near-wall prism layers with controlled y+, model rotating wheels, and correlate against rolling-road wind-tunnel data before making performance claims.

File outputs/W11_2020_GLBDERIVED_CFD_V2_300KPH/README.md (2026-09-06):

# W11 2020 GLB-derived CFD correction — 300 km/h

This release replaces the boxy primitive surrogate with a watertight full-car CFD surface derived directly from the supplied W11 GLB.

## Start here

1. `W11_SOURCE_WITH_SOLVER_DERIVED_CONTINUOUS_AIRFLOW.glb` — exact textured source car plus continuous solver-integrated airflow and animated direction pulses.
2. `W11_SOURCE_TO_CFD_SURFACE_OVERLAY.glb` — direct source-versus-CFD geometry overlay.
3. `W11_2020_GLBDERIVED_CFD_SURFACE.glb` — corrected standalone CFD shell.
4. `CORRECTION_AND_CFD_REPORT.md` — explanation, CFD method, results and limits.
5. `FIGURES/SOLVER_DERIVED_CONTINUOUS_STREAMLINES.png` — continuous solved airflow in side and top projection.
6. [Interactive W11 aerodynamic lab](https://veervverma.github.io/electric-vehicle-design-evolution/wind-tunnel.html) — browser presentation of the detailed W11 with automatic and keyboard-controlled Drive mode, 40 solved paths, camera presets and clearly identified tracing guides.

The CFD geometry is source-faithful, not proprietary Mercedes CAD. The force solution is screening-only and did not pass its force-Cauchy target.

## Interactive visualization limits

The browser lab is an original implementation inspired by the mode-based interaction of Patrick Heintzmann's public Formula demo; it does not copy that site's code, car asset or branding. Cyan and green paths are drawn from `CFD_RESULTS/SOLVER_DERIVED_STREAMLINES.json`. Because the nine floor-seeded paths terminate upstream in the unconverged screening field, orange lines add an explicitly disclosed visual guide from ahead of the front wing to each solver-derived floor/diffuser path. The speed slider changes particle motion and equation-based dynamic pressure (`q = 1/2 rho V^2`); it does not rerun CFD, alter the 300 km/h path geometry, or provide force validation.

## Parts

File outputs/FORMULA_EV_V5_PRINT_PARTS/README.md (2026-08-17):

# Formula EV V5 — separate 55-part STL print release

Every V5 physical part exported separately for slicing, material assignment, selective reprinting, and assembly planning.

## Recommended use

Use `PARTS_AND_MATERIALS.csv` as the authoritative quantity/material list and the numbered files as individual print jobs.

## Units

Millimeters. Confirm scale on import because STL itself does not record units.

## Files

| File | Format | Purpose |
|---|---:|---|
| [`01_enhanced_monocoque.stl`](01_enhanced_monocoque.stl) | STL | Separate triangle-mesh part for 01 enhanced monocoque; STL does not store units. |
| [`02_sensor_nose_cone.stl`](02_sensor_nose_cone.stl) | STL | Separate triangle-mesh part for 02 sensor nose cone; STL does not store units. |
| [`03_sculpted_sidepods_and_radiator_ducts.stl`](03_sculpted_sidepods_and_radiator_ducts.stl) | STL | Separate triangle-mesh part for 03 sculpted sidepods and radiator ducts; STL does not store units. |
| [`04_rear_wing_mainplane.stl`](04_rear_wing_mainplane.stl) | STL | Separate triangle-mesh part for 04 rear wing mainplane; STL does not store units. |
| [`05_drs_flap_animated.stl`](05_drs_flap_animated.stl) | STL | Separate triangle-mesh part for 05 drs flap animated; STL does not store units. |
| [`06_drs_actuator.stl`](06_drs_actuator.stl) | STL | Separate triangle-mesh part for 06 drs actuator; STL does not store units. |
| [`07_enhanced_halo.stl`](07_enhanced_halo.stl) | STL | Separate triangle-mesh part for 07 enhanced halo; STL does not store units. |
| [`08_detailed_cockpit.stl`](08_detailed_cockpit.stl) | STL | Separate triangle-mesh part for 08 detailed cockpit; STL does not store units. |
| [`09_front_pushrod_suspension.stl`](09_front_pushrod_suspension.stl) | STL | Separate triangle-mesh part for 09 front pushrod suspension; STL does not store units. |
| [`10_rear_pushrod_suspension.stl`](10_rear_pushrod_suspension.stl) | STL | Separate triangle-mesh part for 10 rear pushrod suspension; STL does not store units. |
| [`11_battery_modules_and_busbars.stl`](11_battery_modules_and_busbars.stl) | STL | Separate triangle-mesh part for 11 battery modules and busbars; STL does not store units. |
| [`12_motor_gearbox_and_cooling.stl`](12_motor_gearbox_and_cooling.stl) | STL | Separate triangle-mesh part for 12 motor gearbox and cooling; STL does not store units. |
| [`13_inverter_and_hv_connectors.stl`](13_inverter_and_hv_connectors.stl) | STL | Separate triangle-mesh part for 13 inverter and hv connectors; STL does not store units. |
| [`14_radiator_cooling_system.stl`](14_radiator_cooling_system.stl) | STL | Separate triangle-mesh part for 14 radiator cooling system; STL does not store units. |
| [`15_telemetry_antennas.stl`](15_telemetry_antennas.stl) | STL | Separate triangle-mesh part for 15 telemetry antennas; STL does not store units. |
| [`16_front_left_slick_tire.stl`](16_front_left_slick_tire.stl) | STL | Separate triangle-mesh part for 16 front left slick tire; STL does not store units. |
| [`17_front_left_detailed_rim.stl`](17_front_left_detailed_rim.stl) | STL | Separate triangle-mesh part for 17 front left detailed rim; STL does not store units. |
| [`18_front_left_drilled_brake_rotor.stl`](18_front_left_drilled_brake_rotor.stl) | STL | Separate triangle-mesh part for 18 front left drilled brake rotor; STL does not store units. |
| [`19_front_left_center_lock.stl`](19_front_left_center_lock.stl) | STL | Separate triangle-mesh part for 19 front left center lock; STL does not store units. |
| [`20_front_right_slick_tire.stl`](20_front_right_slick_tire.stl) | STL | Separate triangle-mesh part for 20 front right slick tire; STL does not store units. |
| [`21_front_right_detailed_rim.stl`](21_front_right_detailed_rim.stl) | STL | Separate triangle-mesh part for 21 front right detailed rim; STL does not store units. |
| [`22_front_right_drilled_brake_rotor.stl`](22_front_right_drilled_brake_rotor.stl) | STL | Separate triangle-mesh part for 22 front right drilled brake rotor; STL does not store units. |
| [`23_front_right_center_lock.stl`](23_front_right_center_lock.stl) | STL | Separate triangle-mesh part for 23 front right center lock; STL does not store units. |
| [`24_rear_left_slick_tire.stl`](24_rear_left_slick_tire.stl) | STL | Separate triangle-mesh part for 24 rear left slick tire; STL does not store units. |
| [`25_rear_left_detailed_rim.stl`](25_rear_left_detailed_rim.stl) | STL | Separate triangle-mesh part for 25 rear left detailed rim; STL does not store units. |
| [`26_rear_left_drilled_brake_rotor.stl`](26_rear_left_drilled_brake_rotor.stl) | STL | Separate triangle-mesh part for 26 rear left drilled brake rotor; STL does not store units. |
| [`27_rear_left_center_lock.stl`](27_rear_left_center_lock.stl) | STL | Separate triangle-mesh part for 27 rear left center lock; STL does not store units. |
| [`28_rear_right_slick_tire.stl`](28_rear_right_slick_tire.stl) | STL | Separate triangle-mesh part for 28 rear right slick tire; STL does not store units. |
| [`29_rear_right_detailed_rim.stl`](29_rear_right_detailed_rim.stl) | STL | Separate triangle-mesh part for 29 rear right detailed rim; STL does not store units. |
| [`30_rear_right_drilled_brake_rotor.stl`](30_rear_right_drilled_brake_rotor.stl) | STL | Separate triangle-mesh part for 30 rear right drilled brake rotor; STL does not store units. |
| [`31_rear_right_center_lock.stl`](31_rear_right_center_lock.stl) | STL | Separate triangle-mesh part for 31 rear right center lock; STL does not store units. |
| [`32_22_upper_floor_body.stl`](32_22_upper_floor_body.stl) | STL | Separate triangle-mesh part for 32 22 upper floor body; STL does not store units. |
| [`33_23_left_venturi_tunnel.stl`](33_23_left_venturi_tunnel.stl) | STL | Separate triangle-mesh part for 33 23 left venturi tunnel; STL does not store units. |
| [`34_24_right_venturi_tunnel.stl`](34_24_right_venturi_tunnel.stl) | STL | Separate triangle-mesh part for 34 24 right venturi tunnel; STL does not store units. |
| [`35_25_left_inlet_fences_x4.stl`](35_25_left_inlet_fences_x4.stl) | STL | Separate triangle-mesh part for 35 25 left inlet fences x4; STL does not store units. |
| [`36_26_right_inlet_fences_x4.stl`](36_26_right_inlet_fences_x4.stl) | STL | Separate triangle-mesh part for 36 26 right inlet fences x4; STL does not store units. |
| [`37_27_left_floor_edge_wing.stl`](37_27_left_floor_edge_wing.stl) | STL | Separate triangle-mesh part for 37 27 left floor edge wing; STL does not store units. |
| [`38_28_right_floor_edge_wing.stl`](38_28_right_floor_edge_wing.stl) | STL | Separate triangle-mesh part for 38 28 right floor edge wing; STL does not store units. |
| [`39_29_central_plank.stl`](39_29_central_plank.stl) | STL | Separate triangle-mesh part for 39 29 central plank; STL does not store units. |
| [`40_30_titanium_skid_set.stl`](40_30_titanium_skid_set.stl) | STL | Separate triangle-mesh part for 40 30 titanium skid set; STL does not store units. |
| [`41_31_bib_tea_tray.stl`](41_31_bib_tea_tray.stl) | STL | Separate triangle-mesh part for 41 31 bib tea tray; STL does not store units. |
| [`42_32_left_diffuser.stl`](42_32_left_diffuser.stl) | STL | Separate triangle-mesh part for 42 32 left diffuser; STL does not store units. |
| [`43_33_right_diffuser.stl`](43_33_right_diffuser.stl) | STL | Separate triangle-mesh part for 43 33 right diffuser; STL does not store units. |
| [`44_34_diffuser_strakes.stl`](44_34_diffuser_strakes.stl) | STL | Separate triangle-mesh part for 44 34 diffuser strakes; STL does not store units. |
| [`45_35_boat_tail_keel.stl`](45_35_boat_tail_keel.stl) | STL | Separate triangle-mesh part for 45 35 boat tail keel; STL does not store units. |
| [`46_36_rear_wake_fences.stl`](46_36_rear_wake_fences.stl) | STL | Separate triangle-mesh part for 46 36 rear wake fences; STL does not store units. |
| [`47_37_floor_stays.stl`](47_37_floor_stays.stl) | STL | Separate triangle-mesh part for 47 37 floor stays; STL does not store units. |
| [`48_fixed_front_wing_mainplane.stl`](48_fixed_front_wing_mainplane.stl) | STL | Separate triangle-mesh part for 48 fixed front wing mainplane; STL does not store units. |
| [`49_left_active_flap_level_1.stl`](49_left_active_flap_level_1.stl) | STL | Separate triangle-mesh part for 49 left active flap level 1; STL does not store units. |
| [`50_left_active_flap_level_2.stl`](50_left_active_flap_level_2.stl) | STL | Separate triangle-mesh part for 50 left active flap level 2; STL does not store units. |
| [`51_left_active_flap_level_3.stl`](51_left_active_flap_level_3.stl) | STL | Separate triangle-mesh part for 51 left active flap level 3; STL does not store units. |
| [`52_right_active_flap_level_1.stl`](52_right_active_flap_level_1.stl) | STL | Separate triangle-mesh part for 52 right active flap level 1; STL does not store units. |
| [`53_right_active_flap_level_2.stl`](53_right_active_flap_level_2.stl) | STL | Separate triangle-mesh part for 53 right active flap level 2; STL does not store units. |
| [`54_right_active_flap_level_3.stl`](54_right_active_flap_level_3.stl) | STL | Separate triangle-mesh part for 54 right active flap level 3; STL does not store units. |
| [`55_six_channel_front_wing_actuator.stl`](55_six_channel_front_wing_actuator.stl) | STL | Separate triangle-mesh part for 55 six channel front wing actuator; STL does not store units. |
| [`PARTS_AND_MATERIALS.csv`](PARTS_AND_MATERIALS.csv) | CSV | Structured data or manifest table: parts and materials. |
| [`READ_ME_FIRST.txt`](READ_ME_FIRST.txt) | TXT | Documentation, assumptions, guide, or report: read me first. |

## Limitations

Test-fit joints and use suitable rods/fasteners for practical moving mechanisms; this is an educational print kit.

Return to the [repository version history](../../VERSIONS.md).

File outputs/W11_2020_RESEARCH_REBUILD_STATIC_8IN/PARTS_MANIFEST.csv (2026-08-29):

file | part | quantity | length_mm | width_mm | height_mm | material
STL_PRINT_PARTS/01_reinforced_upper_body.stl | Reinforced W11 upper body | 1 | 153.000 | 54.000 | 32.800 | White body
STL_PRINT_PARTS/02_removable_nose.stl | Removable W11 nose | 1 | 35.200 | 14.400 | 10.300 | White body
STL_PRINT_PARTS/03_cockpit_insert.stl | Cockpit insert | 1 | 31.000 | 18.000 | 17.200 | Cockpit
STL_PRINT_PARTS/04_static_halo.stl | Static titanium-style halo | 1 | 42.747 | 25.538 | 14.504 | Black carbon
STL_PRINT_PARTS/05_static_front_wing.stl | Static front wing | 1 | 27.768 | 72.300 | 15.000 | Black carbon
STL_PRINT_PARTS/06_static_rear_wing.stl | Static rear wing | 1 | 33.640 | 57.200 | 23.130 | Black carbon
STL_PRINT_PARTS/07_2020_flat_stepped_floor_diffuser.stl | 2020 flat stepped floor and diffuser | 1 | 137.700 | 52.000 | 10.675 | Black carbon
STL_PRINT_PARTS/08_four_stack_bargeboards.stl | Four-stack bargeboards | 1 | 26.775 | 52.574 | 14.000 | Black carbon
STL_PRINT_PARTS/09_carbon_honeycomb_survival_cell.stl | Carbon honeycomb survival cell | 1 | 96.000 | 27.000 | 25.300 | White body
STL_PRINT_PARTS/10_front_impact_structure.stl | Front impact structure | 1 | 32.500 | 14.000 | 9.300 | White body
STL_PRINT_PARTS/11_side_impact_structures.stl | Side impact structures | 1 | 40.589 | 47.240 | 7.350 | Black carbon
STL_PRINT_PARTS/12_v6_turbo_hybrid_power_unit.stl | V6 turbo hybrid power unit study | 1 | 27.500 | 18.400 | 19.000 | HV orange
STL_PRINT_PARTS/13_compact_energy_store.stl | Compact energy store | 1 | 18.000 | 15.000 | 6.900 | Battery
STL_PRINT_PARTS/14_transaxle_gearbox.stl | Rear transaxle and gearbox | 1 | 31.000 | 21.000 | 15.000 | Electronics
STL_PRINT_PARTS/15_rear_impact_structure.stl | Rear impact structure | 1 | 24.750 | 9.000 | 10.000 | Aluminum
STL_PRINT_PARTS/16_front_pushrod_suspension.stl | Front pushrod suspension and DAS study | 1 | 26.427 | 57.000 | 18.841 | Aluminum
STL_PRINT_PARTS/17_rear_swept_pullrod_suspension.stl | Rear swept pullrod suspension | 1 | 29.255 | 57.000 | 14.000 | Aluminum
STL_PRINT_PARTS/18_rolling_wheel_x4.stl | Rolling wheel | 4 | 25.900 | 10.600 | 25.900 | Tire
STL_PRINT_PARTS/19_axle_pin_x4.stl | Axle pin | 4 | 2.000 | 11.500 | 2.000 | Aluminum
STL_PRINT_PARTS/20_wheel_retainer_x4.stl | Wheel retainer | 4 | 4.400 | 2.600 | 4.400 | Accent

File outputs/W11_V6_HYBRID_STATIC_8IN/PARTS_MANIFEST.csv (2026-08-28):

file | part | quantity | length_mm | width_mm | height_mm | material
STL_PRINT_PARTS/01_reinforced_upper_body.stl | Reinforced upper body | 1 | 153.000 | 54.000 | 32.800 | White body
STL_PRINT_PARTS/02_removable_nose_crashbox.stl | Removable nose and crash box | 1 | 35.200 | 14.400 | 10.300 | White body
STL_PRINT_PARTS/03_cockpit_insert.stl | Cockpit insert | 1 | 31.000 | 18.000 | 17.200 | Cockpit
STL_PRINT_PARTS/04_static_halo.stl | Static halo | 1 | 42.747 | 25.538 | 14.504 | Black carbon
STL_PRINT_PARTS/05_static_front_wing.stl | Static multi-element front wing | 1 | 27.768 | 72.300 | 15.000 | Black carbon
STL_PRINT_PARTS/06_static_rear_wing.stl | Static rear wing | 1 | 33.640 | 57.200 | 23.130 | Black carbon
STL_PRINT_PARTS/07_twin_venturi_floor.stl | Twin Venturi floor and diffuser | 1 | 162.000 | 58.283 | 12.750 | Black carbon
STL_PRINT_PARTS/08_structural_ev_chassis.stl | Structural EV chassis | 1 | 157.000 | 26.927 | 17.475 | Aluminum
STL_PRINT_PARTS/09_low_energy_store.stl | Low energy store | 1 | 75.000 | 21.000 | 7.350 | Battery
STL_PRINT_PARTS/10_rear_motor_gearbox.stl | Rear motor and gearbox | 1 | 26.500 | 16.000 | 16.000 | HV orange
STL_PRINT_PARTS/11_inverter_controller.stl | Inverter and controller | 1 | 22.500 | 15.000 | 7.000 | Electronics
STL_PRINT_PARTS/12_front_static_suspension.stl | Front static suspension and steering rack | 1 | 26.205 | 57.100 | 20.035 | Aluminum
STL_PRINT_PARTS/13_rear_static_suspension.stl | Rear static suspension | 1 | 26.205 | 57.100 | 20.035 | Aluminum
STL_PRINT_PARTS/14_rolling_wheel_x4.stl | Rolling wheel | 4 | 25.900 | 10.600 | 25.900 | Tire
STL_PRINT_PARTS/15_axle_pin_x4.stl | Axle pin | 4 | 2.000 | 11.500 | 2.000 | Aluminum
STL_PRINT_PARTS/16_wheel_retainer_x4.stl | Wheel retainer | 4 | 4.400 | 2.600 | 4.400 | Accent

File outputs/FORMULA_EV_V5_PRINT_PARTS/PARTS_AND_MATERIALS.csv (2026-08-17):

part_number | filename | part_name | recommended_material | size_mm
1 | 01_enhanced_monocoque.stl | Enhanced monocoque | PETG | (170.0, 42, 30.5)
2 | 02_sensor_nose_cone.stl | Sensor nose cone | PETG | (58.5, 26, 11.0)
3 | 03_sculpted_sidepods_and_radiator_ducts.stl | Sculpted sidepods and radiator ducts | PETG | (79.0, 106, 20.49)
4 | 04_rear_wing_mainplane.stl | Rear wing mainplane | PETG | (40.89, 125.0, 46.24)
5 | 05_drs_flap_animated.stl | DRS flap animated | PETG | (19.2, 108.0, 4.4)
6 | 06_drs_actuator.stl | DRS actuator | PETG | (10.26, 4.4, 25.06)
7 | 07_enhanced_halo.stl | Enhanced halo | PETG | (48.0, 42.0, 23.5)
8 | 08_detailed_cockpit.stl | Detailed cockpit | PETG | (66.0, 25.0, 24.75)
9 | 09_front_pushrod_suspension.stl | Front pushrod suspension | PETG | (44.05, 132.0, 24.16)
10 | 10_rear_pushrod_suspension.stl | Rear pushrod suspension | PETG | (44.06, 132.0, 24.16)
11 | 11_battery_modules_and_busbars.stl | Battery modules and busbars | PETG | (96.0, 30.0, 13.25)
12 | 12_motor_gearbox_and_cooling.stl | Motor gearbox and cooling | PETG | (43.0, 90.0, 30.99)
13 | 13_inverter_and_hv_connectors.stl | Inverter and HV connectors | PETG | (28.4, 25.0, 11.5)
14 | 14_radiator_cooling_system.stl | Radiator cooling system | PETG | (28.0, 87.0, 18.0)
15 | 15_telemetry_antennas.stl | Telemetry antennas | PETG | (52.8, 4.0, 32.0)
16 | 16_front_left_slick_tire.stl | Front left slick tire | TPU_95A | (36.7, 36.7, 13.9)
17 | 17_front_left_detailed_rim.stl | Front left detailed rim | PETG | (27.4, 27.4, 10.75)
18 | 18_front_left_drilled_brake_rotor.stl | Front left drilled brake rotor | PETG | (21.6, 21.6, 4.4)
19 | 19_front_left_center_lock.stl | Front left center lock | PETG | (11.6, 11.6, 5.7)
20 | 20_front_right_slick_tire.stl | Front right slick tire | TPU_95A | (36.7, 36.7, 13.9)
21 | 21_front_right_detailed_rim.stl | Front right detailed rim | PETG | (27.4, 27.4, 10.75)
22 | 22_front_right_drilled_brake_rotor.stl | Front right drilled brake rotor | PETG | (21.6, 21.6, 4.4)
23 | 23_front_right_center_lock.stl | Front right center lock | PETG | (11.6, 11.6, 5.7)
24 | 24_rear_left_slick_tire.stl | Rear left slick tire | TPU_95A | (36.7, 36.7, 13.9)
25 | 25_rear_left_detailed_rim.stl | Rear left detailed rim | PETG | (27.4, 27.4, 10.75)
26 | 26_rear_left_drilled_brake_rotor.stl | Rear left drilled brake rotor | PETG | (21.6, 21.6, 4.4)
27 | 27_rear_left_center_lock.stl | Rear left center lock | PETG | (11.6, 11.6, 5.7)
28 | 28_rear_right_slick_tire.stl | Rear right slick tire | TPU_95A | (36.7, 36.7, 13.9)
29 | 29_rear_right_detailed_rim.stl | Rear right detailed rim | PETG | (27.4, 27.4, 10.75)
30 | 30_rear_right_drilled_brake_rotor.stl | Rear right drilled brake rotor | PETG | (21.6, 21.6, 4.4)
31 | 31_rear_right_center_lock.stl | Rear right center lock | PETG | (11.6, 11.6, 5.7)
32 | 32_22_upper_floor_body.stl | 22_upper_floor_body | PETG | (147.0, 75.4, 9.0)
33 | 33_23_left_venturi_tunnel.stl | 23_left_venturi_tunnel | PETG | (137.16, 27.1, 18.2)
34 | 34_24_right_venturi_tunnel.stl | 24_right_venturi_tunnel | PETG | (137.16, 27.1, 18.2)
35 | 35_25_left_inlet_fences_x4.stl | 25_left_inlet_fences_x4 | PETG | (32.05, 32.24, 8.35)
36 | 36_26_right_inlet_fences_x4.stl | 26_right_inlet_fences_x4 | PETG | (32.05, 32.24, 8.35)
37 | 37_27_left_floor_edge_wing.stl | 27_left_floor_edge_wing | PETG | (118.74, 10.79, 9.98)
38 | 38_28_right_floor_edge_wing.stl | 28_right_floor_edge_wing | PETG | (118.74, 10.79, 9.98)
39 | 39_29_central_plank.stl | 29_central_plank | PETG | (132.0, 13.0, 3.75)
40 | 40_30_titanium_skid_set.stl | 30_titanium_skid_set | PETG | (112.0, 9.0, 1.5)
41 | 41_31_bib_tea_tray.stl | 31_bib_tea_tray | PETG | (22.0, 32, 8.0)
42 | 42_32_left_diffuser.stl | 32_left_diffuser | PETG | (48.88, 31, 20.25)
43 | 43_33_right_diffuser.stl | 33_right_diffuser | PETG | (48.88, 31, 20.25)
44 | 44_34_diffuser_strakes.stl | 34_diffuser_strakes | PETG | (44, 64, 19)
45 | 45_35_boat_tail_keel.stl | 35_boat_tail_keel | PETG | (47.56, 15.99, 15.92)
46 | 46_36_rear_wake_fences.stl | 36_rear_wake_fences | PETG | (22.66, 85.66, 7.52)
47 | 47_37_floor_stays.stl | 37_floor_stays | PETG | (37.4, 77.7, 14.7)
48 | 48_fixed_front_wing_mainplane.stl | Fixed front-wing mainplane | PETG | (40.73, 151.0, 27.0)
49 | 49_left_active_flap_level_1.stl | Left active flap level 1 | PETG | (18.8, 65.5, 8.98)
50 | 50_left_active_flap_level_2.stl | Left active flap level 2 | PETG | (16.8, 59.5, 9.92)
51 | 51_left_active_flap_level_3.stl | Left active flap level 3 | PETG | (14.8, 51.5, 10.86)
52 | 52_right_active_flap_level_1.stl | Right active flap level 1 | PETG | (18.8, 65.5, 8.98)
53 | 53_right_active_flap_level_2.stl | Right active flap level 2 | PETG | (16.8, 59.5, 9.92)
54 | 54_right_active_flap_level_3.stl | Right active flap level 3 | PETG | (14.8, 51.5, 10.86)
55 | 55_six_channel_front_wing_actuator.stl | Six-channel front-wing actuator | PETG | (17.68, 28.41, 19.86)

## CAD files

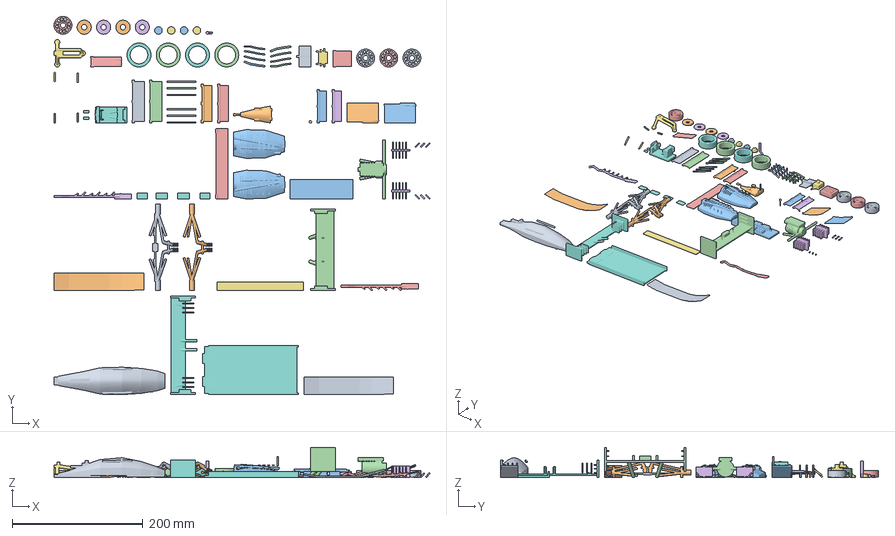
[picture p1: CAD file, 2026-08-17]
outputs/formula_ev_v5_all_active_flaps/FORMULA_EV_V5_COMPLETE_PRINT_KIT_COMPATIBILITY.3mf
574.6 x 578.1 x 46.2 mm
01_Enhanced monocoque
02_Sensor nose cone
03_Sculpted sidepods and radiator ducts
04_Rear wing mainplane
05_DRS flap animated
06_DRS actuator
07_Enhanced halo
08_Detailed cockpit
09_Front pushrod suspension
10_Rear pushrod suspension
11_Battery modules and busbars
12_Motor gearbox and cooling
13_Inverter and HV connectors
14_Radiator cooling system
15_Telemetry antennas
16_Front left slick tire
17_Front left detailed rim
18_Front left drilled brake rotor
19_Front left center lock
20_Front right slick tire
21_Front right detailed rim
22_Front right drilled brake rotor
23_Front right center lock
24_Rear left slick tire
25_Rear left detailed rim
26_Rear left drilled brake rotor
27_Rear left center lock
28_Rear right slick tire
29_Rear right detailed rim
30_Rear right drilled brake rotor
31_Rear right center lock
32_22_upper_floor_body
33_23_left_venturi_tunnel
34_24_right_venturi_tunnel
35_25_left_inlet_fences_x4
36_26_right_inlet_fences_x4
37_27_left_floor_edge_wing
38_28_right_floor_edge_wing
39_29_central_plank
40_30_titanium_skid_set
41_31_bib_tea_tray
42_32_left_diffuser
43_33_right_diffuser
44_34_diffuser_strakes
45_35_boat_tail_keel
46_36_rear_wake_fences
47_37_floor_stays
48_Fixed front-wing mainplane
49_Left active flap level 1
50_Left active flap level 2
51_Left active flap level 3
52_Right active flap level 1
53_Right active flap level 2
54_Right active flap level 3
55_Six-channel front-wing actuator

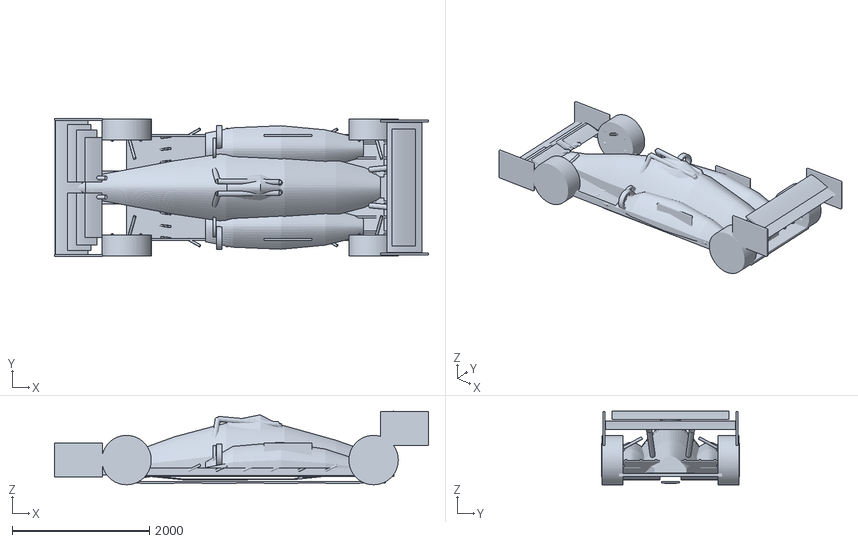
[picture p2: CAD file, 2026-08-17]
outputs/V6_CFD_REBUILD/V6_FULL_SCALE_CFD_SURFACES.stl
5450.0 x 2010.0 x 1072.2

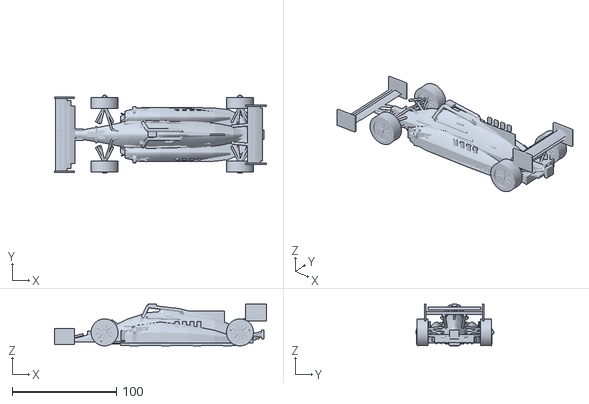
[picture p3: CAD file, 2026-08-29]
outputs/W11_2020_RESEARCH_REBUILD_STATIC_8IN/W11_2020_PRINTABLE_ASSEMBLED_REFERENCE.stl
203.2 x 74.8 x 40.0

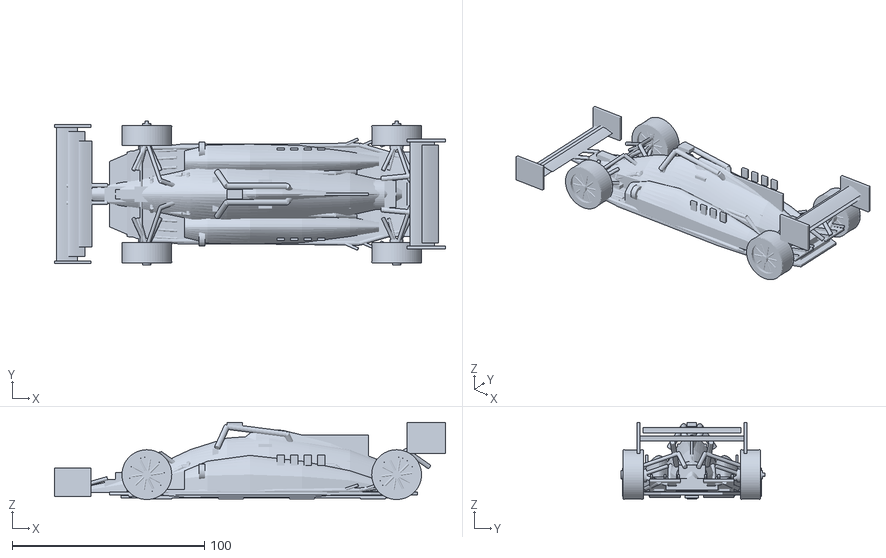
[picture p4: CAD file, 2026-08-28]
outputs/W11_V6_HYBRID_STATIC_8IN/W11_V6_PRINTABLE_ASSEMBLED_REFERENCE.stl
203.2 x 74.8 x 40.0

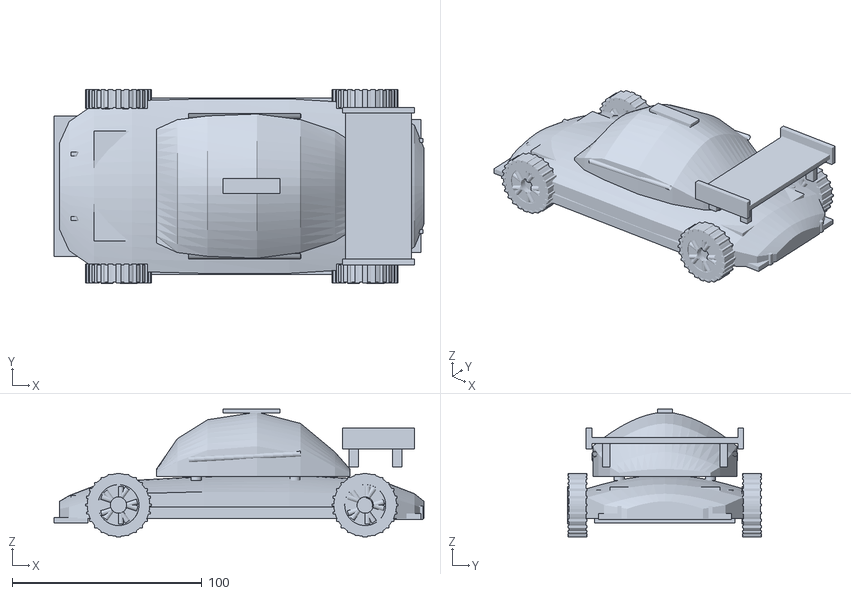
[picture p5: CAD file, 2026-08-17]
outputs/advanced_ev_sedan/advanced_sedan_assembled_reference.stl
195.0 x 102.4 x 67.2

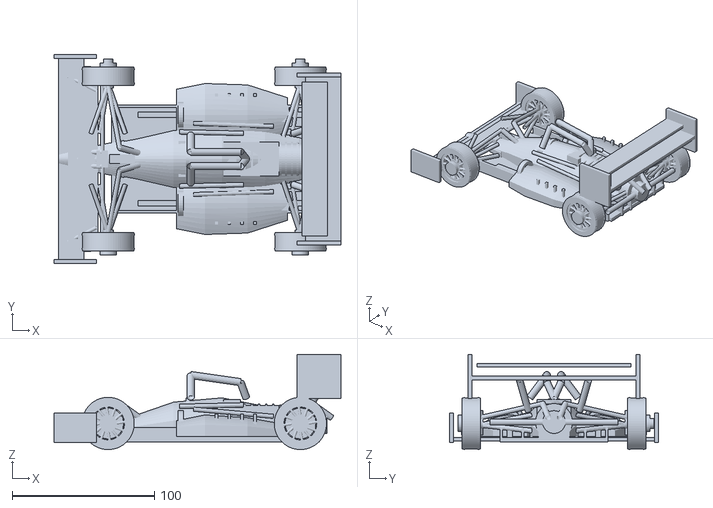
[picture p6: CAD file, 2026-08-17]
outputs/formula_ev_prototype/FORMULA_EV_COMPLETE_ASSEMBLED.stl
201.5 x 147.0 x 66.8

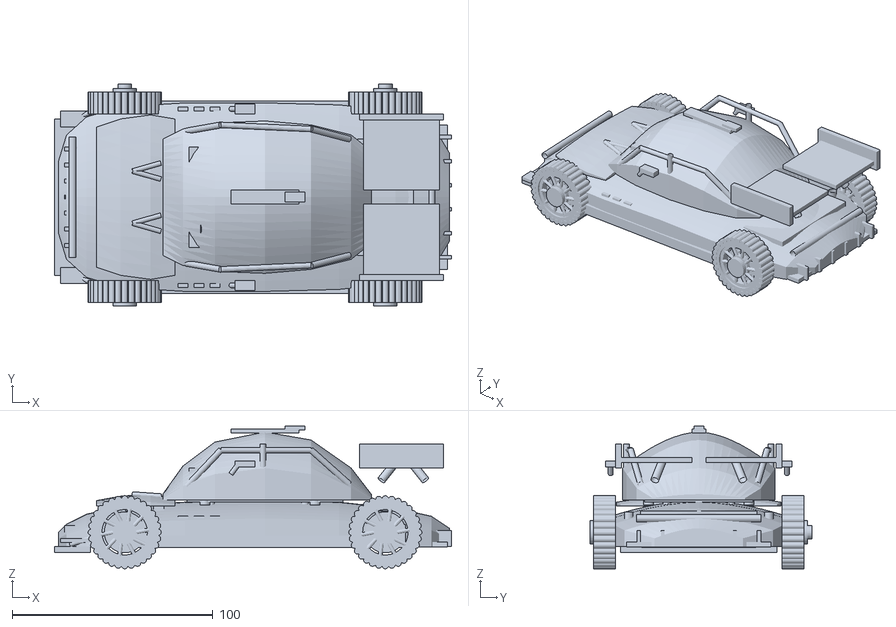
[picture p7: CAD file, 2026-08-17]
outputs/advanced_ev_sedan_v2/advanced_sedan_v2_assembled_reference.stl
198.0 x 110.7 x 71.3

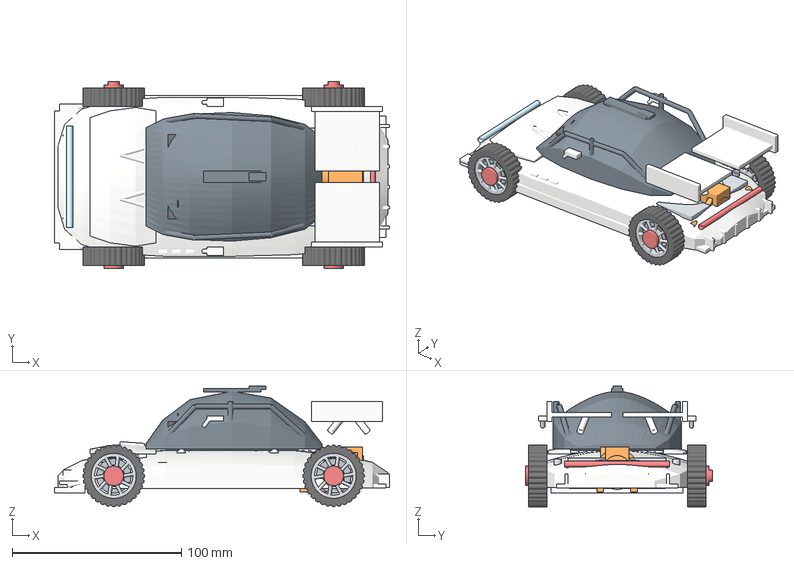
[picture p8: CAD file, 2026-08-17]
outputs/portfolio_ev_sedan_v3/EV_SEDAN_V3_ASSEMBLED_SHOWCASE.3mf
198.0 x 110.7 x 71.3 mm
White aerodynamic monocoque
Graphite fastback glasshouse
White removable vented hood
Four-seat interior
Swan-neck rear wing
Front steering suspension
Rear suspension
front_left TPU tire
front_left ten-spoke rim
front_left brake rotor
front_left wheel retainer
front_right TPU tire
front_right ten-spoke rim
front_right brake rotor
front_right wheel retainer
rear_left TPU tire
rear_left ten-spoke rim
rear_left brake rotor
rear_left wheel retainer
rear_right TPU tire
rear_right ten-spoke rim
rear_right brake rotor
rear_right wheel retainer
Front LED light bar
Rear LED light bar
Left aero mirror
Right aero mirror
Skateboard battery pack
Rear motor and reduction gearbox
Inverter and vehicle controller
Charging and service unit

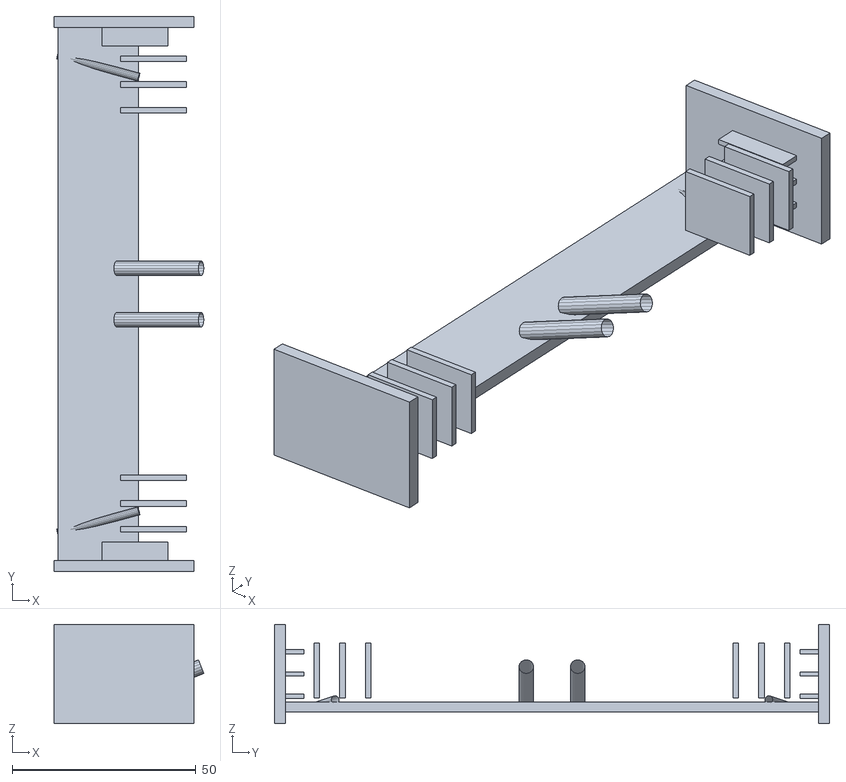
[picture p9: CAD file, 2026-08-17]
outputs/FORMULA_EV_V5_PRINT_PARTS/48_fixed_front_wing_mainplane.stl
40.7 x 151.0 x 27.0

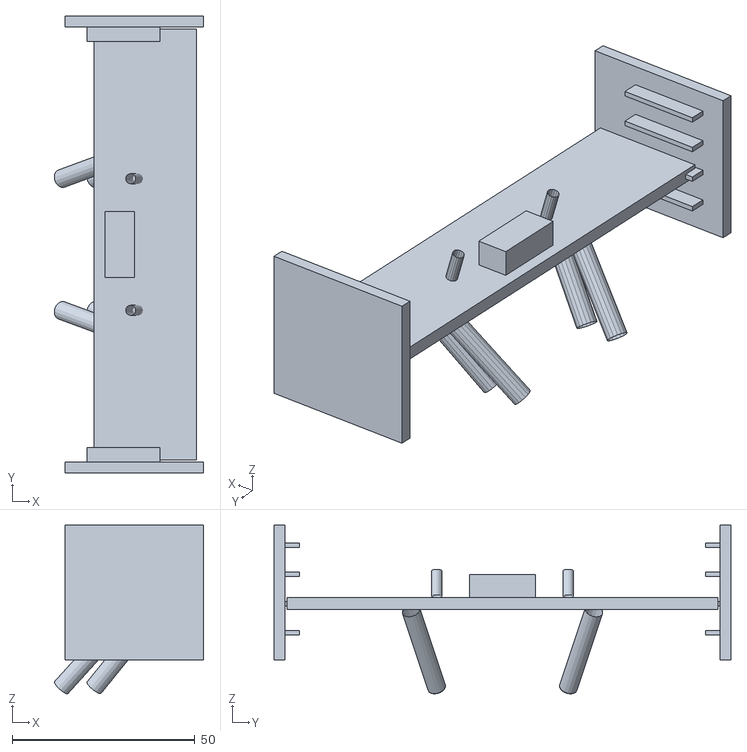
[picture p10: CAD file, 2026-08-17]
outputs/FORMULA_EV_V5_PRINT_PARTS/04_rear_wing_mainplane.stl
40.9 x 125.0 x 46.2

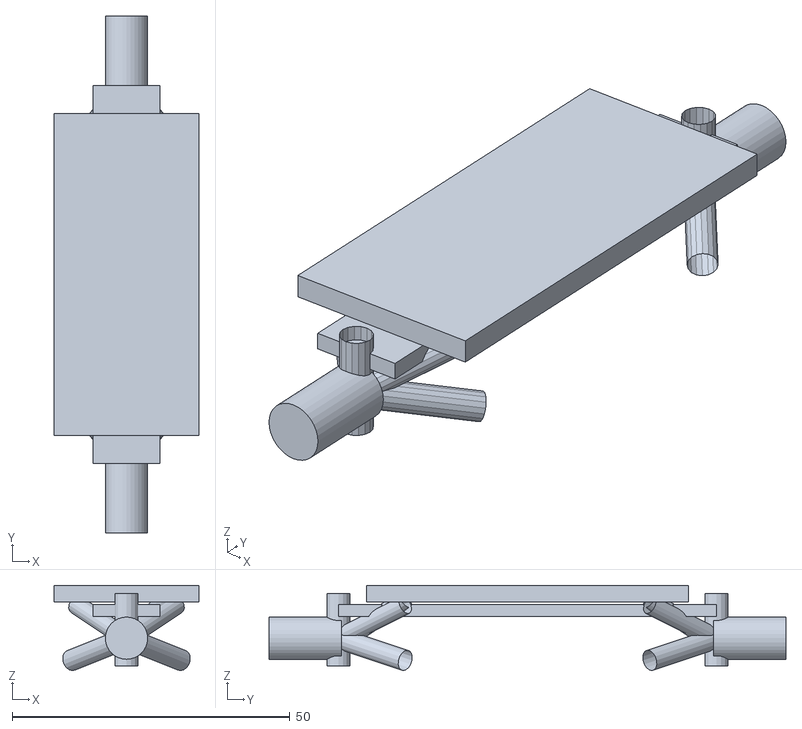
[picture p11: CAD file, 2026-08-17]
outputs/advanced_ev_sedan/suspension_axle_module_x2.stl
26.0 x 93.0 x 15.3

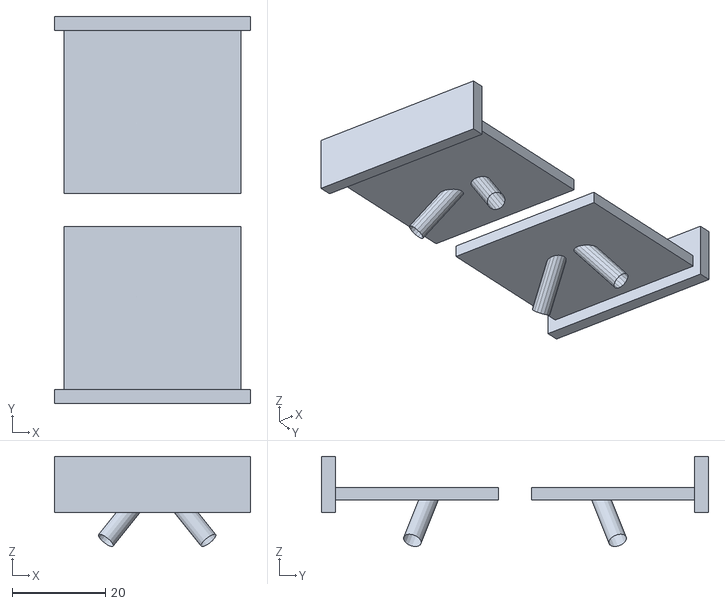
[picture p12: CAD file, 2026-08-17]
outputs/advanced_ev_sedan_v2/05_swan_neck_rear_wing.stl
42.0 x 83.0 x 19.3

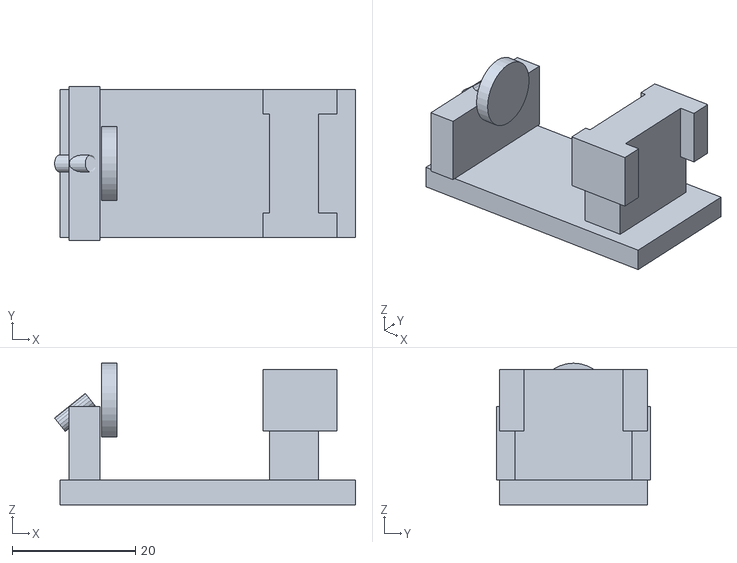
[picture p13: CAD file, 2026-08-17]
outputs/formula_ev_prototype/08_cockpit_insert.stl
48.9 x 25.0 x 23.0

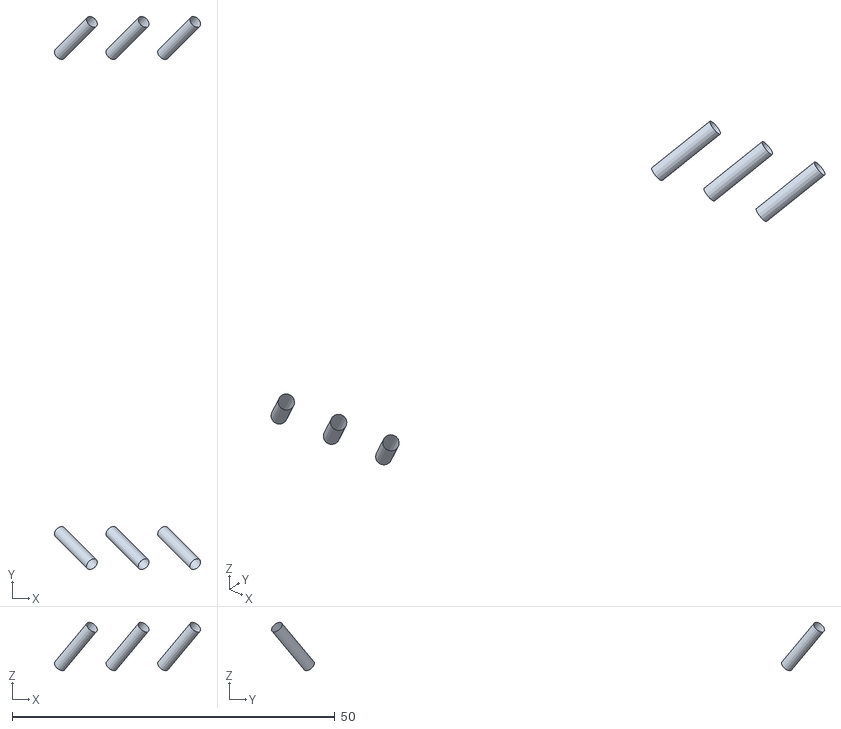
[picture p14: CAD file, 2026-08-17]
outputs/FORMULA_EV_V5_PRINT_PARTS/46_36_rear_wake_fences.stl
22.7 x 85.7 x 7.52

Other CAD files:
outputs/formula_ev_v5_all_active_flaps/FORMULA_EV_V5_COMPLETE_PRINT_KIT_55_PARTS.3mf
outputs/formula_ev_prototype/FORMULA_EV_ASSEMBLED_COLOR.3mf
outputs/portfolio_ev_sedan_v3/EV_SEDAN_V3_COMPLETE_ASSEMBLED.stl
outputs/portfolio_ev_sedan_v3/EV_SEDAN_V3_EXPLODED_TECHNICAL.3mf
outputs/FORMULA_EV_V5_PRINT_PARTS/01_enhanced_monocoque.stl
outputs/FORMULA_EV_V5_PRINT_PARTS/02_sensor_nose_cone.stl
outputs/FORMULA_EV_V5_PRINT_PARTS/03_sculpted_sidepods_and_radiator_ducts.stl
outputs/FORMULA_EV_V5_PRINT_PARTS/05_drs_flap_animated.stl
outputs/FORMULA_EV_V5_PRINT_PARTS/06_drs_actuator.stl
outputs/FORMULA_EV_V5_PRINT_PARTS/07_enhanced_halo.stl
outputs/FORMULA_EV_V5_PRINT_PARTS/08_detailed_cockpit.stl
outputs/FORMULA_EV_V5_PRINT_PARTS/09_front_pushrod_suspension.stl
outputs/FORMULA_EV_V5_PRINT_PARTS/10_rear_pushrod_suspension.stl
outputs/FORMULA_EV_V5_PRINT_PARTS/11_battery_modules_and_busbars.stl
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

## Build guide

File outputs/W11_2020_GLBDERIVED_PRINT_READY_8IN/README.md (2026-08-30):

# W11 GLB-derived print-ready release — exact 8-inch length

This folder converts the corrected source-GLB-derived W11 aerodynamic shell into a strengthened static display model measuring **203.2 × 71.975 × 40.560 mm**. The main release is a single watertight, positive-volume, connected body so the complete car can be quoted and printed as one object.

## Recommended files

### Lowest-assembly-cost option

- `W11_8IN_ONE_PIECE_PRINT_READY_MM.3mf` — recommended single-object print project with explicit millimeter units, already positioned inside a 220 × 220 mm bed.
- `W11_8IN_ONE_PIECE_PRINT_READY_MM.stl` — the same one-piece model; choose **millimeters** if the slicer asks.
- `W11_8IN_ONE_PIECE_PRINT_READY_PREVIEW.glb` — browser preview of the printable geometry.

The one-piece model is exactly **8.000 inches / 203.2 mm long**, has one connected body, and is watertight. It uses a 0.40 mm printer-scale solidification grid plus one-cell reinforcement around fragile wing edges and junctions.

### Lower-support-risk alternative

- `W11_8IN_THREE_SECTION_PRINT_PLATE_MM.3mf` — front, center and rear sections arranged across approximately 211.2 mm of a 220 mm bed.
- `THREE_SECTION_OPTION/` — the same three sections as separate watertight STL files.

The sections use flat capped butt joints. Bond them with medium CA glue or a small amount of two-part epoxy after dry fitting.

## CFD airflow visualization

- `W11_8IN_CFD_AIRFLOW_POINTS_FRONTWING_TO_DIFFUSER.glb` — the 8-inch printable car with digital CFD streamlines and airflow points.
- `W11_8IN_CFD_AIRFLOW_POINTS_PREVIEW.png` — side and top projections.

Colors in the GLB:

- Blue: overall solved-field airflow.
- Green: floor and diffuser-seeded paths.
- Orange/red: nine additional continuous paths traced from the front-wing region, along the floor and through the diffuser.

The airflow tubes and points are intentionally **not fused into the printable car**. They are digital analysis markers and would otherwise become floating or support-heavy geometry that changes the car's aerodynamic shape. The car itself remains fully printable.

## FDM recommendations

- Material: PLA or PLA+ for the easiest detailed display print; PETG for greater impact resistance.
- Nozzle: 0.25 mm preferred for wing and floor detail; 0.40 mm is supported.
- Layer height: 0.12–0.16 mm.
- Walls: 3; top/bottom layers: 4–5; infill: 12–18% gyroid.
- Supports: organic/tree supports from the build plate, especially beneath the front wing, suspension and rear wing.
- Adhesion: 5–8 mm brim around tyres and front-wing contact areas.
- Orientation: keep the imported upright orientation with z = 0 on the bed.

The one-piece car fits a 220 mm bed with approximately **8.4 mm longitudinal margin at each end**. Actual print price depends on the service's support strategy; one piece avoids assembly labor, while the three-section version can reduce difficult supports and failed-print risk.

## Validation limits

`PRINT_VALIDATION.json` records dimensions, triangle counts, connectivity and topology. This is a static display derivative, not a moving-wheel model. The associated CFD run remains screening-only and did not meet its force-convergence target; the airflow paths are useful for visualization but are not validated Mercedes W11 performance data.

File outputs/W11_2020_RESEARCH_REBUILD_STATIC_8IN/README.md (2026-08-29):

# W11 2020 OPEN-SOURCE RESEARCH REBUILD - STATIC 8-INCH MODEL

This release corrects the previous hybrid model using the FIA's 2020 rules, Mercedes' published chassis specification, and contemporary Formula 1 technical reporting. The largest correction is the floor: the W11 used the 2020 flat/reference-plane and step-plane architecture with a plank, bargeboards, floor-edge devices and a short diffuser. It did **not** have the deep 2022-style twin Venturi tunnels used in the earlier V6 study.

The model remains static. The four wheels rotate on separate printed axle pins.

## Start here

- `W11_2020_REFERENCE_RESEARCH_ASSEMBLED.glb` - detailed supplied exterior plus the corrected named chassis/floor systems.
- `W11_2020_REFERENCE_RESEARCH_EXPLODED.glb` - lifted exterior showing the revised systems.
- `W11_2020_PRINTABLE_ASSEMBLED.glb` - exact printable procedural assembly.
- `W11_2020_PRINTABLE_EXPLODED.glb` - all printable systems separated.
- `W11_2020_FLAT_STEPPED_FLOOR_ONLY.glb` - reference plane, step plane, plank, bargeboards, rear-tyre vanes and diffuser.
- `W11_2020_CHASSIS_ONLY.glb` - monocoque, impact structures, hybrid powertrain and W11-inspired suspension.
- `W11_2020_ALL_PRINT_PARTS_220MM_PLATE.3mf` - all 29 physical pieces arranged on one 220 x 220 mm plate.

## Finished size and units

Overall length: **203.2 mm / 8.00 in**. Approximate assembled envelope: 203.20 x 74.80 x 40.05 mm. Import STL files as **millimetres**. The 3MF stores millimetres explicitly.

## Historically informed corrections

- Removed the 2022-style twin Venturi tunnels.
- Added 2020 reference-plane and 50 mm step-plane logic at scale.
- Added the 300 mm regulation plank width at scale, with print-thickened skids.
- Replaced the long tunnel diffuser with a short multi-channel 2020 diffuser.
- Added four-element Spa-spec bargeboard stacks and three vanes ahead of each rear tyre.
- Replaced the open EV frame with a carbon-fibre/honeycomb survival-cell study.
- Replaced the flat battery and hub-motor layout with a compact hybrid energy store, V6 turbo-hybrid power-unit study, rear transaxle and rear impact structure.
- Revised suspension to front pushrod and rear pullrod layouts, including the W11's unusually swept lower rear wishbone geometry.

## Printing

- PLA+ is the simplest material for the body, floor, chassis and wings.
- PETG is useful for axle pins, retainers and suspension; TPU 95A is optional for wheels.
- 0.4 mm nozzle, 0.16-0.20 mm layers, 3-4 walls and 18-25% gyroid infill.
- Use tree/build-plate supports for the body, halo, bargeboards, wings and suspension.
- Print the floor broad upper face down. The flat lower surfaces, plank and diffuser will then remain visible after assembly.

## Assembly order

1. Fit the compact energy store, power unit and transaxle around the survival cell.
2. Add the front, side and rear impact structures.
3. Attach this chassis assembly to the upper face of the flat stepped floor.
4. Install front pushrod and rear swept pullrod suspension at X=-53.6 mm and X=+76.2 mm.
5. Glue axle pins into the uprights, slide on the wheels, and glue retainers only to the pin tips. Leave 0.25-0.35 mm lateral play.
6. Fit cockpit and halo, then install the upper body, nose and static wings.

## Accuracy boundary

The floor rules and public external features are source-backed, but Mercedes did not publish production CAD, laminate schedules, exact internal bulkheads, or full aerodynamic surface coordinates. The hidden chassis and powertrain geometry is therefore an informed educational reconstruction, not a reverse-engineered manufacturing replica or validated CFD model. Small legal-scale details were thickened to approximately 0.7-0.8 mm where required for FDM printing.

See `OPEN_SOURCE_RESEARCH_AND_DESIGN_CHANGES.md` for the source-by-source evidence and dimensional translation.

## Exterior reference credit

Original Sketchfab model: `mercedec f1 2020` by Kevin Love SketchFab / Tyler_Kevin, CC BY 4.0: https://sketchfab.com/3d-models/mercedec-f1-2020-0d97207d829441ba95952598f84e8d63

Source GLB SHA-256: `f63aa9ab4a1225080b5968ebbaa7aeb1bc909b506e1cae9d41df6a08b38ec11f`

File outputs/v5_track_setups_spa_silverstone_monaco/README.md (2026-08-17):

# Formula EV V5 — Spa, Silverstone, and Monaco setup study

Track-specific conceptual setup changes and downforce points for three circuits with different speed and load requirements.

## Recommended use

Use the report for narrative and the two CSV files for setup parameters and track-specific downforce data.

## Units

SI units and degrees as labeled in the report and CSV files.

## Files

| File | Format | Purpose |
|---|---:|---|
| [`V5_THREE_TRACK_SETUP_REPORT.txt`](V5_THREE_TRACK_SETUP_REPORT.txt) | TXT | Documentation, assumptions, guide, or report: v5 three track setup report. |
| [`V5_TRACK_SETUP_PARAMETERS.csv`](V5_TRACK_SETUP_PARAMETERS.csv) | CSV | Structured data or manifest table: v5 track setup parameters. |
| [`V5_TRACK_SPECIFIC_DOWNFORCE.csv`](V5_TRACK_SPECIFIC_DOWNFORCE.csv) | CSV | Structured data or manifest table: v5 track specific downforce. |

## Limitations

Starting hypotheses only; not a seven-post, driver-in-loop, tire, energy, or validated track model.

Return to the [repository version history](../../VERSIONS.md).

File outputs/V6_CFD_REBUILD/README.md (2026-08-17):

# Formula EV V6 — full-scale CFD-preparation rebuild

Separate parametric V6 geometry pipeline with 20 named aerodynamic/mechanical surface groups, full-scale preview, part manifest, and a prepared 300 km/h OpenFOAM case.

## Recommended use

Use `V6_FULL_SCALE_CFD_PREVIEW.glb` for viewing, `geometry/` for separated surfaces, and `OpenFOAM_83ms/` as the unsolved CFD starting case.

## Units

Top-level and `geometry/` STL files are millimeters; OpenFOAM `triSurface` copies are meters. Combined model length is approximately 5,450 mm.

## Files

| File | Format | Purpose |
|---|---:|---|
| [`geometry/body.stl`](geometry/body.stl) | STL | Separate triangle-mesh part for body; STL does not store units. |
| [`geometry/canopy.stl`](geometry/canopy.stl) | STL | Separate triangle-mesh part for canopy; STL does not store units. |
| [`geometry/cooling.stl`](geometry/cooling.stl) | STL | Separate triangle-mesh part for cooling; STL does not store units. |
| [`geometry/diffuser.stl`](geometry/diffuser.stl) | STL | Separate triangle-mesh part for diffuser; STL does not store units. |
| [`geometry/floor.stl`](geometry/floor.stl) | STL | Separate triangle-mesh part for floor; STL does not store units. |
| [`geometry/frontFlaps.stl`](geometry/frontFlaps.stl) | STL | Separate triangle-mesh part for frontflaps; STL does not store units. |
| [`geometry/frontWing.stl`](geometry/frontWing.stl) | STL | Separate triangle-mesh part for frontwing; STL does not store units. |
| [`geometry/halo.stl`](geometry/halo.stl) | STL | Separate triangle-mesh part for halo; STL does not store units. |
| [`geometry/nose.stl`](geometry/nose.stl) | STL | Separate triangle-mesh part for nose; STL does not store units. |
| [`geometry/plank.stl`](geometry/plank.stl) | STL | Separate triangle-mesh part for plank; STL does not store units. |
| [`geometry/rearFlap.stl`](geometry/rearFlap.stl) | STL | Separate triangle-mesh part for rearflap; STL does not store units. |
| [`geometry/rearWing.stl`](geometry/rearWing.stl) | STL | Separate triangle-mesh part for rearwing; STL does not store units. |
| [`geometry/sidepods.stl`](geometry/sidepods.stl) | STL | Separate triangle-mesh part for sidepods; STL does not store units. |
| [`geometry/skids.stl`](geometry/skids.stl) | STL | Separate triangle-mesh part for skids; STL does not store units. |
| [`geometry/suspension.stl`](geometry/suspension.stl) | STL | Separate triangle-mesh part for suspension; STL does not store units. |
| [`geometry/venturi.stl`](geometry/venturi.stl) | STL | Separate triangle-mesh part for venturi; STL does not store units. |
| [`geometry/wheelFL.stl`](geometry/wheelFL.stl) | STL | Separate triangle-mesh part for wheelfl; STL does not store units. |
| [`geometry/wheelFR.stl`](geometry/wheelFR.stl) | STL | Separate triangle-mesh part for wheelfr; STL does not store units. |
| [`geometry/wheelRL.stl`](geometry/wheelRL.stl) | STL | Separate triangle-mesh part for wheelrl; STL does not store units. |
| [`geometry/wheelRR.stl`](geometry/wheelRR.stl) | STL | Separate triangle-mesh part for wheelrr; STL does not store units. |
| [`OpenFOAM_83ms/0/k`](OpenFOAM_83ms/0/k) | FILE | Project support file: k. |
| [`OpenFOAM_83ms/0/nut`](OpenFOAM_83ms/0/nut) | FILE | Project support file: nut. |
| [`OpenFOAM_83ms/0/omega`](OpenFOAM_83ms/0/omega) | FILE | Project support file: omega. |
| [`OpenFOAM_83ms/0/p`](OpenFOAM_83ms/0/p) | FILE | Project support file: p. |
| [`OpenFOAM_83ms/0/U`](OpenFOAM_83ms/0/U) | FILE | Project support file: u. |
| [`OpenFOAM_83ms/Allrun`](OpenFOAM_83ms/Allrun) | FILE | Project support file: allrun. |
| [`OpenFOAM_83ms/constant/transportProperties`](OpenFOAM_83ms/constant/transportProperties) | FILE | Project support file: transportproperties. |
| [`OpenFOAM_83ms/constant/triSurface/body.stl`](OpenFOAM_83ms/constant/triSurface/body.stl) | STL | Separate triangle-mesh part for body; STL does not store units. |
| [`OpenFOAM_83ms/constant/triSurface/canopy.stl`](OpenFOAM_83ms/constant/triSurface/canopy.stl) | STL | Separate triangle-mesh part for canopy; STL does not store units. |
| [`OpenFOAM_83ms/constant/triSurface/cooling.stl`](OpenFOAM_83ms/constant/triSurface/cooling.stl) | STL | Separate triangle-mesh part for cooling; STL does not store units. |
| [`OpenFOAM_83ms/constant/triSurface/diffuser.stl`](OpenFOAM_83ms/constant/triSurface/diffuser.stl) | STL | Separate triangle-mesh part for diffuser; STL does not store units. |
| [`OpenFOAM_83ms/constant/triSurface/floor.stl`](OpenFOAM_83ms/constant/triSurface/floor.stl) | STL | Separate triangle-mesh part for floor; STL does not store units. |
| [`OpenFOAM_83ms/constant/triSurface/frontFlaps.stl`](OpenFOAM_83ms/constant/triSurface/frontFlaps.stl) | STL | Separate triangle-mesh part for frontflaps; STL does not store units. |
| [`OpenFOAM_83ms/constant/triSurface/frontWing.stl`](OpenFOAM_83ms/constant/triSurface/frontWing.stl) | STL | Separate triangle-mesh part for frontwing; STL does not store units. |
| [`OpenFOAM_83ms/constant/triSurface/halo.stl`](OpenFOAM_83ms/constant/triSurface/halo.stl) | STL | Separate triangle-mesh part for halo; STL does not store units. |
| [`OpenFOAM_83ms/constant/triSurface/nose.stl`](OpenFOAM_83ms/constant/triSurface/nose.stl) | STL | Separate triangle-mesh part for nose; STL does not store units. |
| [`OpenFOAM_83ms/constant/triSurface/plank.stl`](OpenFOAM_83ms/constant/triSurface/plank.stl) | STL | Separate triangle-mesh part for plank; STL does not store units. |
| [`OpenFOAM_83ms/constant/triSurface/rearFlap.stl`](OpenFOAM_83ms/constant/triSurface/rearFlap.stl) | STL | Separate triangle-mesh part for rearflap; STL does not store units. |
| [`OpenFOAM_83ms/constant/triSurface/rearWing.stl`](OpenFOAM_83ms/constant/triSurface/rearWing.stl) | STL | Separate triangle-mesh part for rearwing; STL does not store units. |
| [`OpenFOAM_83ms/constant/triSurface/sidepods.stl`](OpenFOAM_83ms/constant/triSurface/sidepods.stl) | STL | Separate triangle-mesh part for sidepods; STL does not store units. |
| [`OpenFOAM_83ms/constant/triSurface/skids.stl`](OpenFOAM_83ms/constant/triSurface/skids.stl) | STL | Separate triangle-mesh part for skids; STL does not store units. |
| [`OpenFOAM_83ms/constant/triSurface/suspension.stl`](OpenFOAM_83ms/constant/triSurface/suspension.stl) | STL | Separate triangle-mesh part for suspension; STL does not store units. |
| [`OpenFOAM_83ms/constant/triSurface/venturi.stl`](OpenFOAM_83ms/constant/triSurface/venturi.stl) | STL | Separate triangle-mesh part for venturi; STL does not store units. |
| [`OpenFOAM_83ms/constant/triSurface/wheelFL.stl`](OpenFOAM_83ms/constant/triSurface/wheelFL.stl) | STL | Separate triangle-mesh part for wheelfl; STL does not store units. |
| [`OpenFOAM_83ms/constant/triSurface/wheelFR.stl`](OpenFOAM_83ms/constant/triSurface/wheelFR.stl) | STL | Separate triangle-mesh part for wheelfr; STL does not store units. |
| [`OpenFOAM_83ms/constant/triSurface/wheelRL.stl`](OpenFOAM_83ms/constant/triSurface/wheelRL.stl) | STL | Separate triangle-mesh part for wheelrl; STL does not store units. |
| [`OpenFOAM_83ms/constant/triSurface/wheelRR.stl`](OpenFOAM_83ms/constant/triSurface/wheelRR.stl) | STL | Separate triangle-mesh part for wheelrr; STL does not store units. |
| [`OpenFOAM_83ms/constant/turbulenceProperties`](OpenFOAM_83ms/constant/turbulenceProperties) | FILE | Project support file: turbulenceproperties. |
| [`OpenFOAM_83ms/README.txt`](OpenFOAM_83ms/README.txt) | TXT | Documentation, assumptions, guide, or report: readme. |
| [`OpenFOAM_83ms/system/blockMeshDict`](OpenFOAM_83ms/system/blockMeshDict) | FILE | Project support file: blockmeshdict. |
| [`OpenFOAM_83ms/system/controlDict`](OpenFOAM_83ms/system/controlDict) | FILE | Project support file: controldict. |
| [`OpenFOAM_83ms/system/fvSchemes`](OpenFOAM_83ms/system/fvSchemes) | FILE | Project support file: fvschemes. |
| [`OpenFOAM_83ms/system/fvSolution`](OpenFOAM_83ms/system/fvSolution) | FILE | Project support file: fvsolution. |
| [`OpenFOAM_83ms/system/snappyHexMeshDict`](OpenFOAM_83ms/system/snappyHexMeshDict) | FILE | Project support file: snappyhexmeshdict. |
| [`OpenFOAM_83ms/system/surfaceFeatureExtractDict`](OpenFOAM_83ms/system/surfaceFeatureExtractDict) | FILE | Project support file: surfacefeatureextractdict. |
| [`V6_ASSUMPTIONS_AND_LIMITATIONS.txt`](V6_ASSUMPTIONS_AND_LIMITATIONS.txt) | TXT | Documentation, assumptions, guide, or report: v6 assumptions and limitations. |
| [`V6_COMPLETE_REBUILD_PACKAGE.zip`](V6_COMPLETE_REBUILD_PACKAGE.zip) | ZIP | Convenience archive containing the v6 complete rebuild package package. |
| [`V6_FULL_SCALE_CFD_PREVIEW.glb`](V6_FULL_SCALE_CFD_PREVIEW.glb) | GLB | Browser-viewable binary glTF model for the v6 full scale cfd preview component/system. |
| [`V6_FULL_SCALE_CFD_SURFACES.stl`](V6_FULL_SCALE_CFD_SURFACES.stl) | STL | Combined triangle-mesh reference of the complete design; read this folder's unit and print limitations. |
| [`V6_OPENFOAM_CFD_PACKAGE.zip`](V6_OPENFOAM_CFD_PACKAGE.zip) | ZIP | Convenience archive containing the v6 openfoam cfd package package. |
| [`V6_PART_MANIFEST.csv`](V6_PART_MANIFEST.csv) | CSV | Structured data or manifest table: v6 part manifest. |
| [`V6_REBUILD_README.md`](V6_REBUILD_README.md) | MD | Documentation, assumptions, guide, or report: v6 rebuild readme. |

## Limitations

CFD preparation only. Components were not production-booleaned, and surface checks, meshing, solver runs, mesh independence, and experimental correlation were not completed.

Return to the [repository version history](../../VERSIONS.md).

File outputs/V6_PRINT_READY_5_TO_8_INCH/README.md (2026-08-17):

# Formula EV V6 — repaired 5-inch and 8-inch print release

Consumer-printer derivatives created after the full-scale V6 CFD STL proved too large and topologically unsuitable for slicing. Models were repaired, reinforced, scaled, voxel-solidified, and audited.

## Recommended use

Use the `PRINT_READY_SOLID_MM` 3MF or STL files. The 8-inch version preserves stronger details; the 5-inch version fits smaller beds.

## Units

Millimeters. 5-inch length ≈127 mm; 8-inch length =203.2 mm. Prefer 3MF because it explicitly stores millimeter units.

## Files

| File | Format | Purpose |
|---|---:|---|
| [`MESH_VALIDATION.txt`](MESH_VALIDATION.txt) | TXT | Documentation, assumptions, guide, or report: mesh validation. |
| [`READ_ME_FIRST.txt`](READ_ME_FIRST.txt) | TXT | Documentation, assumptions, guide, or report: read me first. |
| [`V6_5IN_PRINT_READY_SOLID_MM.3mf`](V6_5IN_PRINT_READY_SOLID_MM.3mf) | 3MF | 3MF print project preserving object structure and millimeter units where authored. |
| [`V6_5IN_PRINT_READY_SOLID_MM.stl`](V6_5IN_PRINT_READY_SOLID_MM.stl) | STL | Validated manifold STL prepared for FDM slicing; import as millimeters. |
| [`V6_5IN_SMOOTH_REPAIRED_MM.stl`](V6_5IN_SMOOTH_REPAIRED_MM.stl) | STL | Smoother repaired reference STL retaining intersecting CFD-derived shells; solid version is preferred for slicing. |
| [`V6_8IN_PRINT_READY_SOLID_MM.3mf`](V6_8IN_PRINT_READY_SOLID_MM.3mf) | 3MF | 3MF print project preserving object structure and millimeter units where authored. |
| [`V6_8IN_PRINT_READY_SOLID_MM.stl`](V6_8IN_PRINT_READY_SOLID_MM.stl) | STL | Validated manifold STL prepared for FDM slicing; import as millimeters. |
| [`V6_8IN_SMOOTH_REPAIRED_MM.stl`](V6_8IN_SMOOTH_REPAIRED_MM.stl) | STL | Smoother repaired reference STL retaining intersecting CFD-derived shells; solid version is preferred for slicing. |

## Limitations

One-piece static display derivatives. Active flaps do not move, and small details remain challenging on a typical 0.4 mm FDM nozzle.

Return to the [repository version history](../../VERSIONS.md).

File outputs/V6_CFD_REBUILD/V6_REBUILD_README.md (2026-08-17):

# Formula EV V6 CFD rebuild

This package contains a full-scale, parametric Formula-style EV concept rebuilt as 20 separately named closed surface components. Its main aerodynamic features are a twin-Venturi floor, throat regions, plank/skids, progressive diffuser, multi-element front wing with separate active flaps, rear wing with separate active flap, sidepods, cooling elements, suspension and four wheels.

## Main files

- `V6_FULL_SCALE_CFD_PREVIEW.glb` — assembled visual inspection model with 20 named meshes.
- `V6_FULL_SCALE_CFD_SURFACES.stl` — combined full-scale surface export in millimetres.
- `geometry/*.stl` — 20 separate CAD/printing surface exports in millimetres.
- `OpenFOAM_83ms/` — prepared 300 km/h steady-RANS case; its private `triSurface` copies are already in metres.
- `V6_PART_MANIFEST.csv` — part list, dimensions, triangle counts and SHA-256 hashes.
- `V6_ASSUMPTIONS_AND_LIMITATIONS.txt` — required limitations.

## Baseline OpenFOAM setup

- 83.333 m/s freestream and moving ground
- rotating wheels at 231.48 rad/s
- k-omega SST turbulence model
- local refinement for the floor, Venturi tunnels, diffuser and wings
- five requested prism layers on major aerodynamic surfaces
- force/drag/lift coefficient monitoring

From an OpenFOAM terminal, enter `OpenFOAM_83ms`, make `Allrun` executable, and run it. Inspect with `surfaceCheck` and `checkMesh` first. Mesh-independence, domain-independence, transient/yaw studies and experimental correlation are still required before treating outputs as engineering predictions.

## Important

This is a CFD-preparation model, not a verified race-car design and not a ready-to-print mini assembly. The combined model is full scale; scale and engineer clearances/connectors before fabrication. No CFD solver or production mesher was available in the creation environment, so no genuine CFD result is included.

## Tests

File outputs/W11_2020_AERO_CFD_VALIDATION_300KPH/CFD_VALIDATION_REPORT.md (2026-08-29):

# W11 2020 reference study — aerodynamic visualization, estimates, and CFD screening

## Decision summary

An actual **SU2 8.5.0 steady INC_RANS/SST CFD screening study** was completed at **300 km/h (83.333 m/s)**. It is more rigorous than the earlier illustrative airflow animations, but it is **not a wind-tunnel-correlated prediction of the proprietary Mercedes W11**.

The two moving-ground meshes predict a full-car-equivalent downforce bracket of **6.65–9.49 kN** (**678–968 kgf**) at 300 km/h. The midpoint is **8.07 kN**, with a coarse/medium half-range of **±17.6%**. Because full-car ClA changed **29.9%** from coarse to medium and the medium moving-ground run did not satisfy the specified force-Cauchy threshold, the study **did not achieve mesh independence**. Treat the bracket as screening evidence only, with additional geometry/model uncertainty of at least roughly ±30–40%.

## Run matrix and results

Half-model SU2 coefficients were converted to full-car effective areas as `ClA = 2 × |CL_half| × 1 m²` and `CdA = 2 × CD_half × 1 m²`. Forces use `q = 0.5 ρ V²`, with `ρ = 1.225 kg/m³` and `q = 4253.47 Pa`.

| Case | Nodes | Ground | Full ClA (m²) | Full CdA (m²) | Downforce (kN) | Drag (kN) | Solver status |
|---|---:|---|---:|---:|---:|---:|---|
| coarse_stationary_ground_diagnostic | 59,882 | stationary slip | 0.113 | 0.739 | 0.48 | 3.14 | residual criterion reached |
| medium_stationary_ground_diagnostic | 124,977 | stationary slip | 0.191 | 0.711 | 0.81 | 3.03 | stable final force window |
| coarse_moving_ground | 59,882 | moving wall 83.333 m/s | 2.231 | 2.048 | 9.49 | 8.71 | drag Cauchy 9.74e-5 < 1e-4 |
| medium_moving_ground | 124,977 | moving wall 83.333 m/s | 1.564 | 1.834 | 6.65 | 7.80 | iteration limit; drag Cauchy 5.72e-4 > 1e-4 |

The stationary/slip-ground runs are diagnostics, not vehicle predictions. Their large loss of downforce demonstrates that a moving ground is essential for this ground-effect-sensitive surrogate.

## What was modeled

- Full-scale, half-car symmetry domain: 25 m long × 5 m half-width × 5 m high.
- De-featured public-information surrogate preserving a 2020-era flat/stepped floor, central plank, short diffuser, exposed wheels, sidepod/body volumes, and inverted multi-element wings.
- Steady incompressible RANS with SST V2003m turbulence model.
- Freestream and moving ground: 83.333 m/s.
- Coarse mesh: 59,882 nodes / 266,014 tetrahedra.
- Medium mesh: 124,977 nodes / 601,194 tetrahedra.

## What was not modeled

- Proprietary Mercedes W11 production CAD, hidden floor details, exact ride heights, rake, suspension deflection, or aero-elasticity.
- Rotating wheels, tyre deformation, cooling flow, exhaust plume, leakage, or yaw.
- Near-wall prism layers with verified y+, transient structures, or a high-order production-quality mesh.
- Physical moving-belt wind-tunnel data or track correlation.

## Numerical verification status

| Check | Result |
|---|---|
| Coarse moving-ground force convergence | Pass: drag Cauchy 9.74e-5 < 1e-4 |
| Medium moving-ground force convergence | Not passed: 5.72e-4 > 1e-4 at the iteration limit |
| Grid independence | Not passed: ClA changed 29.9% and CdA changed 10.5% |
| Ground-boundary sensitivity | Demonstrated; stationary ground is unsuitable |
| Wind-tunnel correlation | Not performed |

This completes a reproducible **CFD screening and numerical verification step**, not experimental validation. Physical validation would require a documented scale model, a rolling-road/moving-belt tunnel, wheel rotation, ride-height control, force-balance calibration, repeat runs, and correlation against the same geometry and conditions.

## Equation-based estimate

`W11_EQUATION_BASED_AERO_ESTIMATE.csv` uses an intentionally transparent assumption of `ClA = 4.20 m²` and `CdA = 1.25 m²`, not a measured W11 value. Its nominal 300 km/h result is about 17.86 kN, which is well above this coarse surrogate CFD bracket. That disagreement is useful: it shows why an uncalibrated coefficient assumption must not be presented as validation.

## Files to inspect

- `W11_2020_WHOLE_CAR_AIRFLOW_PRESENTATION.glb` — animated explanatory airflow presentation; particles are illustrative, not CFD streamlines.
- `FIGURES/CFD_SIDEPLANE_VELOCITY.png` — contour from the solved coarse moving-ground SU2 field.
- `FIGURES/CFD_SIDEPLANE_PRESSURE.png` — solved symmetry-plane pressure coefficient contour.
- `FIGURES/CFD_FORCE_CONVERGENCE.png` — force history for all four cases.
- `FIGURES/CFD_MOVING_GROUND_CONVERGENCE.png` — moving-ground cases on a readable force scale.
- `CFD_GRID_AND_FORCE_SUMMARY.csv` — auditable final-window statistics and force conversions.
- `CFD_RESULTS/` — solver histories, logs, and ParaView-readable VTU output.
- `CFD_SU2_CASE/` — SU2 meshes and configuration files.

## Public references and software

- [FIA 2020 Formula One Technical Regulations](https://www.fia.com/file/80070/download)
- [Formula 1 technical analysis of the W11 Spa floor](https://www.formula1.com/en/latest/article/a-close-look-at-the-w11-upgrades-that-show-how-hard-mercedes-are-pushing-to.9gN4Z9e1WyQLz7hofTf46.9gN4Z9e1WyQLz7hofTf46)
- [Formula 1 W11 suspension analysis](https://www.formula1.com/en/latest/article/tech-tuesday-why-das-is-only-the-second-most-impressive-innovation-on-the.2EfeudguxvleJcSV7GJ2TZ)
- [Mercedes-AMG F1 W11 EQ Performance technical specification](https://media.mercedes-benz.com/article/95002cb8-fdee-4190-82fb-c2b00feaf8db)
- [SU2 v8.5.0 release](https://github.com/su2code/SU2/releases/tag/v8.5.0)
- [SU2 incompressible turbulent tutorial](https://su2code.github.io/tutorials/Inc_Turbulent_NACA0012/)
- [Gmsh](https://gmsh.info/)

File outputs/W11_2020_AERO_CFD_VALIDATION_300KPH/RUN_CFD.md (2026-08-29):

# Re-running the SU2 cases

## Software

- SU2 8.5.0: <https://github.com/su2code/SU2/releases/tag/v8.5.0>
- Optional mesh regeneration: Python 3 plus the packages in `requirements_cfd.txt`.

## Solver runs

Run from `CFD_SU2_CASE` so each configuration can find its mesh:

```bash
SU2_CFD -t 8 w11_coarse_moving_final.cfg
SU2_CFD -t 8 w11_medium_moving_ground.cfg
```

The stationary-ground configurations are retained only as diagnostics. SU2 output names in the original configurations differ slightly from the curated names under `CFD_RESULTS`; the report records the mapping.

## Mesh regeneration

From the repository root:

```bash
python -m pip install -r outputs/W11_2020_AERO_CFD_VALIDATION_300KPH/requirements_cfd.txt
python work/build_w11_2020_su2_case.py outputs/W11_2020_AERO_CFD_VALIDATION_300KPH/CFD_SU2_CASE/w11_coarse.su2 0.24
python work/build_w11_2020_su2_case.py outputs/W11_2020_AERO_CFD_VALIDATION_300KPH/CFD_SU2_CASE/w11_medium.su2 0.16
```

Use ParaView to inspect `CFD_RESULTS/*.vtu`. A production study should add prism layers/y+ control, rotating wheels, tighter local refinement, further mesh levels, yaw/ride-height sweeps, and experimental correlation.

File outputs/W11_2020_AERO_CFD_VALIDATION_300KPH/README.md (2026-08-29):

# W11 2020 aerodynamic CFD package — 300 km/h

This folder contains the rerun aerodynamic presentation, equation-based estimate, reproducible SU2 cases, solved CFD output, and numerical verification report for the latest W11 2020 public-reference-based design.

## Headline result

- Actual open-source CFD was run with SU2 8.5.0 using steady incompressible RANS/SST.
- Moving-ground screening bracket at 300 km/h: **6.65–9.49 kN downforce**.
- The result is **not mesh-independent and not wind-tunnel validated**. It is a documented screening estimate, not an exact Mercedes W11 claim.

Start with:

1. [`CFD_VALIDATION_REPORT.md`](CFD_VALIDATION_REPORT.md) — method, results, and limitations.
2. [`W11_2020_WHOLE_CAR_AIRFLOW_PRESENTATION.glb`](W11_2020_WHOLE_CAR_AIRFLOW_PRESENTATION.glb) — browser-viewable animated presentation.
3. [`CFD_GRID_AND_FORCE_SUMMARY.csv`](CFD_GRID_AND_FORCE_SUMMARY.csv) — numeric results.
4. [`RUN_CFD.md`](RUN_CFD.md) — reproducibility instructions.

The GLB airflow particles are explanatory animation. The PNG contours and VTU files come from the solved SU2 field.

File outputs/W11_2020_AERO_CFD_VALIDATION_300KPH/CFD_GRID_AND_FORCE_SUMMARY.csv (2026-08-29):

case | history | mesh | ground | nodes | tets | solver_status | use | iterations | window | cl_half_mean | cl_half_stdev | cd_half_mean | cd_half_stdev | final_rms_pressure_log10 | full_car_ClA_m2 | full_car_CdA_m2 | downforce_N_at_300_kmh | downforce_kgf_at_300_kmh | drag_N_at_300_kmh | aero_power_kW_at_300_kmh | downforce_to_drag
coarse_stationary_ground_diagnostic | history_coarse_stationary.csv | coarse | stationary slip | 59882 | 266014 | residual criterion reached | diagnostic only | 75 | 20 | -0.056539096881 | 0.023835809590337223 | 0.369573582575 | 0.006230255793326192 | -6.001392249 | 0.113078193762 | 0.73914716515 | 480.9749561057291 | 49.045796077735936 | 3143.941935099826 | 261.99516125831883 | 0.1529846816622131
medium_stationary_ground_diagnostic | history_medium_stationary.csv | medium | stationary slip | 124977 | 601194 | stable final force window | diagnostic only | 250 | 20 | -0.095570123954 | 0.003736357645908575 | 0.355738047 | 0.00063677641254371 | -7.215778686 | 0.191140247908 | 0.711476094 | 813.0097350253471 | 82.90392081142359 | 3026.2438026041664 | 252.18698355034718 | 0.2686530854935514
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

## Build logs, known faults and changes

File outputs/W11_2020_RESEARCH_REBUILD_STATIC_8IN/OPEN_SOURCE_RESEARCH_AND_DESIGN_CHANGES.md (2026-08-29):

# OPEN-SOURCE RESEARCH AND DESIGN CHANGES

Research date: 2026-08-28

## What the public evidence supports

### 1. The W11 floor was a 2020 flat/stepped floor, not a 2022 tunnel floor

The FIA 2020 Formula One Technical Regulations, Article 3.7, required the sprung underbody visible from below through the central axle region to lie on either a reference plane or a parallel step plane 50 mm above it. The regulation also specified a 300 mm-wide plank, a diffuser no wider than 1050 mm below the stated height, a maximum 350 mm diffuser extension behind the rear axle in the outer region, and a maximum permitted diffuser-body height of 175 mm in the regulated rear zone.

Source: https://www.fia.com/file/80070/download

Design translation at this model's approximately 1:28.05 scale:

| Full-size rule | True scale | Model implementation |
|---|---:|---:|
| 50 mm step-plane offset | 1.78 mm | 1.8 mm |
| 300 mm plank width | 10.69 mm | 10.7 mm |
| 10 mm plank thickness | 0.36 mm | 0.8 mm, print-thickened |
| 1050 mm diffuser width | 37.42 mm | 37.4-38.0 mm |
| 350 mm diffuser length aft of axle | 12.47 mm | 12.5 mm |
| 175 mm diffuser height | 6.23 mm | approximately 6.2 mm rise |
| 430 mm floor datum aft of front axle | 15.32 mm | 15.3 mm |

This regulatory geometry is why the previous V6 twin-tunnel floor was removed.

### 2. W11 floor edge and bargeboards

Formula 1's September 2020 technical review states that Mercedes' Spa package reduced the lattice-like bargeboard stack from five elements to four and added three vanes ahead of the rear tyre. Those visible features are represented here as separate, printable relief geometry.

Source: https://www.formula1.com/en/latest/article/a-close-look-at-the-w11-upgrades-that-show-how-hard-mercedes-are-pushing-to.9gN4Z9e1WyQLz7hofTf46.9gN4Z9e1WyQLz7hofTf46

### 3. Rear suspension was swept backward to help the diffuser

Formula 1's W11 suspension analysis explains that the lower rear wishbone was swept unusually far rearward. Its front leg mounted well back and the rear leg fed into the rear crash structure, creating more open flow area beside and above the diffuser. The model now uses a narrow-angle, swept lower wishbone and rear pullrod arrangement instead of the earlier symmetric generic module.

Sources:
- https://www.formula1.com/en/latest/article/tech-tuesday-why-das-is-only-the-second-most-impressive-innovation-on-the.2EfeudguxvleJcSV7GJ2TZ
- https://www.formula1.com/en/latest/article/tech-tuesday-how-ferrari-and-hamilton-pushed-mercedes-to-create-the.1zMRmGDpJtpDXrlZBbjIs9

### 4. Chassis and suspension construction

Mercedes' published 2020 technical specification describes a moulded carbon-fibre and honeycomb composite chassis, carbon-fibre bodywork/floor, front carbon wishbones with pushrod-actuated torsion springs and rockers, and rear carbon wishbones with pullrod-actuated inboard springs and dampers. The model now follows that architecture and includes representative impact structures, compact hybrid energy store, power unit and transaxle packaging.

Source: https://media.mercedes-benz.com/article/95002cb8-fdee-4190-82fb-c2b00feaf8db

## Before/after summary

| System | Previous hybrid | Corrected W11 research rebuild |
|---|---|---|
| Main floor | Deep twin Venturi tunnels | Flat reference plane plus raised step plane |
| Floor edge | 2022-style fences | 2020 slots/reliefs, four-stack bargeboards and three rear-tyre vanes |
| Diffuser | Long progressive tunnel diffuser | Short 2020 multi-channel diffuser |
| Chassis | Open frame-like EV rails | Carbon/honeycomb survival-cell study |
| Energy | Flat EV pack | Compact hybrid energy-store packaging |
| Drive unit | Electric motor/gear housing | V6 turbo-hybrid study and rear transaxle |
| Front suspension | Generic static double wishbone | W11-inspired pushrod, multi-link lower arrangement and DAS rack study |
| Rear suspension | Generic symmetric module | Pullrod with swept, narrow-angle lower wishbone and crash-structure pickup |

## Limits

Exact W11 production CAD and internal composite construction remain proprietary. Public photographs and technical reporting support the visible architecture, but not every curvature, laminate, duct or pickup coordinate. This is a source-informed scale study optimized for 3D printing, not an exact Mercedes engineering drawing.

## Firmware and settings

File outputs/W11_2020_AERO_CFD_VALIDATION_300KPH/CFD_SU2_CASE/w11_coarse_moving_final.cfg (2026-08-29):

SOLVER= INC_RANS
KIND_TURB_MODEL= SST
SST_OPTIONS= V2003m
MATH_PROBLEM= DIRECT
RESTART_SOL= YES
TIME_MARCHING= NO

INC_DENSITY_INIT= 1.225
INC_VELOCITY_INIT= ( 83.333333, 0.0, 0.0 )
INC_TEMPERATURE_INIT= 288.15
VISCOSITY_MODEL= CONSTANT_VISCOSITY
MU_CONSTANT= 1.7894E-5

REF_ORIGIN_MOMENT_X= 0.0
REF_ORIGIN_MOMENT_Y= 0.0
REF_ORIGIN_MOMENT_Z= 0.30
REF_LENGTH= 5.0
REF_AREA= 1.0

MARKER_HEATFLUX= ( car, 0.0, ground, 0.0 )
MARKER_FAR= ( inlet, outlet, farfield )
MARKER_SYM= ( symmetry )
SURFACE_MOVEMENT= MOVING_WALL
MARKER_MOVING= ( ground )
SURFACE_TRANSLATION_RATE= 83.333333 0.0 0.0
MARKER_PLOTTING= ( car )
MARKER_MONITORING= ( car )

NUM_METHOD_GRAD= WEIGHTED_LEAST_SQUARES
NUM_METHOD_GRAD_RECON= LEAST_SQUARES
CFL_NUMBER= 3.0
CFL_ADAPT= NO
CFL_ADAPT_PARAM= ( 0.5, 1.25, 0.5, 30.0 )
ITER= 200

LINEAR_SOLVER= FGMRES
LINEAR_SOLVER_INNER= BCGSTAB
LINEAR_SOLVER_PREC= LU_SGS
LINEAR_SOLVER_ERROR= 1E-5
LINEAR_SOLVER_ITER= 10

CONV_NUM_METHOD_FLOW= FDS
MUSCL_FLOW= YES
SLOPE_LIMITER_FLOW= VENKATAKRISHNAN
TIME_DISCRE_FLOW= EULER_IMPLICIT
CONV_NUM_METHOD_TURB= SCALAR_UPWIND
MUSCL_TURB= NO
SLOPE_LIMITER_TURB= VENKATAKRISHNAN
TIME_DISCRE_TURB= EULER_IMPLICIT

CONV_FIELD= DRAG
CONV_RESIDUAL_MINVAL= -12
CONV_STARTITER= 20
CONV_CAUCHY_ELEMS= 30
CONV_CAUCHY_EPS= 1E-4

MESH_FILENAME= w11_coarse.su2
MESH_FORMAT= SU2
TABULAR_FORMAT= CSV
SOLUTION_FILENAME= restart_coarse_moving
CONV_FILENAME= history_coarse_moving_final
RESTART_FILENAME= restart_coarse_moving_final
VOLUME_FILENAME= flow_coarse_moving_final
SURFACE_FILENAME= surface_coarse_moving_final
OUTPUT_WRT_FREQ= 100
SCREEN_WRT_FREQ_INNER= 25
SCREEN_OUTPUT= ( INNER_ITER, RMS_PRESSURE, RMS_VELOCITY-X, RMS_TKE, RMS_DISSIPATION, LIFT, DRAG, CFL_NUMBER )
HISTORY_OUTPUT= ( ITER, RMS_RES, AERO_COEFF, CFL_NUMBER )
VOLUME_OUTPUT= ( COORDINATES, SOLUTION, PRIMITIVE, VORTICITY, QCRITERION )
OUTPUT_FILES= ( RESTART, PARAVIEW, SURFACE_PARAVIEW, CSV )

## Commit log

2026-08-17 Initial commit: EV design evolution archive
    [01_carbon_monocoque.stl, 01_enhanced_monocoque.stl, 01_monocoque_body.stl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]
2026-08-17 Link interactive 3D model gallery
    [FILE_MANIFEST.csv]
2026-08-28 Add static 8-inch W11 V6 hybrid print package
    [01_reinforced_upper_body.stl, 02_removable_nose_crashbox.stl, 03_cockpit_insert.stl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]
2026-08-29 Rebuild W11 chassis and floor from 2020 sources
    [01_reinforced_upper_body.stl, 02_removable_nose.stl, 03_cockpit_insert.stl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]
2026-08-29 Add W11 2020 SU2 aerodynamic screening package
    [CFD_GRID_AND_FORCE_SUMMARY.csv, FILE_MANIFEST.csv, W11_EQUATION_BASED_AERO_ESTIMATE.csv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]
2026-08-29 Replace W11 CFD surrogate with source-derived full-car study
    [FILE_MANIFEST.csv, W11_2020_GLBDERIVED_CFD_SURFACE.stl, history_continue_80.csv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]
2026-08-30 Add exact 8-inch W11 print release and focused CFD airflow paths
    [01_FRONT_SECTION_PRINT_READY_MM.stl, 02_CENTER_SECTION_PRINT_READY_MM.stl, 03_REAR_SECTION_PRINT_READY_MM.stl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]
2026-09-05 Refresh GitHub Pages model catalog without stale cache
    [FILE_MANIFEST.csv]
2026-09-05 Bust Pages viewer cache for latest W11 release
    [FILE_MANIFEST.csv]
2026-09-06 Add interactive W11 aerodynamic lab
    [FILE_MANIFEST.csv]
2026-09-06 Add moving W11 drive mode
    [FILE_MANIFEST.csv]
2026-09-06 Animate W11 wheel geometry
    [FILE_MANIFEST.csv]
